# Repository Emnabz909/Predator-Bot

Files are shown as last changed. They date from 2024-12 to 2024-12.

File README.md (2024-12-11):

# Heat-Seeking Predator Bot

This project involved designing and building an autonomous robot capable of tracking and following a person based on their heat signature. The bot integrates various sensors, actuators, and a custom PCB for hardware interfacing, exemplifying a multidisciplinary approach to mechatronics.

## Table of Contents
1. [Introduction](#introduction)
2. [Specifications](#specifications)
3. [Design Development](#design-development)
   - [Hardware Design](#hardware-design)
   - [Software Design](#software-design)
4. [Results](#results)
5. [Lessons Learned](#lessons-learned)
6. [References](#references)

---

## Introduction
The Heat-Seeking Predator Bot was designed to:
- Detect and follow a person using a thermal camera and IR distance sensor.
- Maintain a proximity range using motor control.
- Demonstrate multitasking capabilities for real-time operation.

The bot was built using an ESP32 FireBeetle microcontroller, with custom PCB and housing, leveraging various sensors and actuators to create a functional prototype.

## Specifications
The bot's key specifications are:
- **Thermal Camera**: Adafruit MLX90640 (20–40°C, ±5°C accuracy).
- **IR Distance Sensor**: Sharp GP2Y0A21YK0F (2–36 inches, ±0.5-inch accuracy).
- **Inertial Measurement Unit (IMU)**: Adafruit BNO055 for motion control.
- **Motors**: N20 DC motors with magnetic encoders and DRV8871 motor drivers.

### Pass/Fail Criteria
- Tracks heat signatures.
- Maintains a 2–36-inch range from objects.
- Streams thermal heatmaps to a web interface.

---

## Design Development

### Hardware Design
The custom PCB was created using KiCAD and included:
- Screw terminals for component connectivity.
- Proper trace sizing for power and heat dissipation.
- Compact layout to minimize weight and improve balance.

The bot’s housing was designed to securely hold all components while minimizing weight-induced friction.

### Software Design
The software was modular, focusing on individual sensor functionality before integration:
- **Thermal Camera**: Detected heat signatures and converted data to ASCII for debugging.
- **IR Distance Sensor**: Measured distance using voltage-to-distance calibration.
- **IMU**: Provided acceleration data to refine motor control.
- **Motor Control**: Implemented PID for speed adjustments.

Due to time constraints, full system integration was not achieved.

---

## Results
While the bot's PCB design required significant revisions, the sensors functioned as expected when tested individually. Challenges included:
- Inadequate motor speed and torque.
- Integration of components due to missing PCB features.

Despite these setbacks, the project provided valuable hands-on experience.

---

## Lessons Learned
Key takeaways include:
1. **Early Planning**: A thorough design phase and literature review are essential.
2. **PCB Design**: Focus on component connectivity, power handling, and adequate debugging options.
3. **Prototyping**: Iterative testing is vital for identifying and resolving design flaws.

---

## References
- [Adafruit MLX90640 GitHub Repository](https://github.com/adafruit/Adafruit_MLX90640)
- [Adafruit BNO055 GitHub Repository](https://github.com/adafruit/Adafruit_BNO055)
- [Predator Bot Repository](https://github.com/Emnabz909/Predator-Bot)

---

## Acknowledgments
This project was completed as part of ME 507 at Cal Poly San Luis Obispo. Special thanks to the Mechatronics Department for providing resources and support.

---

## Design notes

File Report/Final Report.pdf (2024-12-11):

# ME 507 Term Project

Heat Seeking Predator Bot

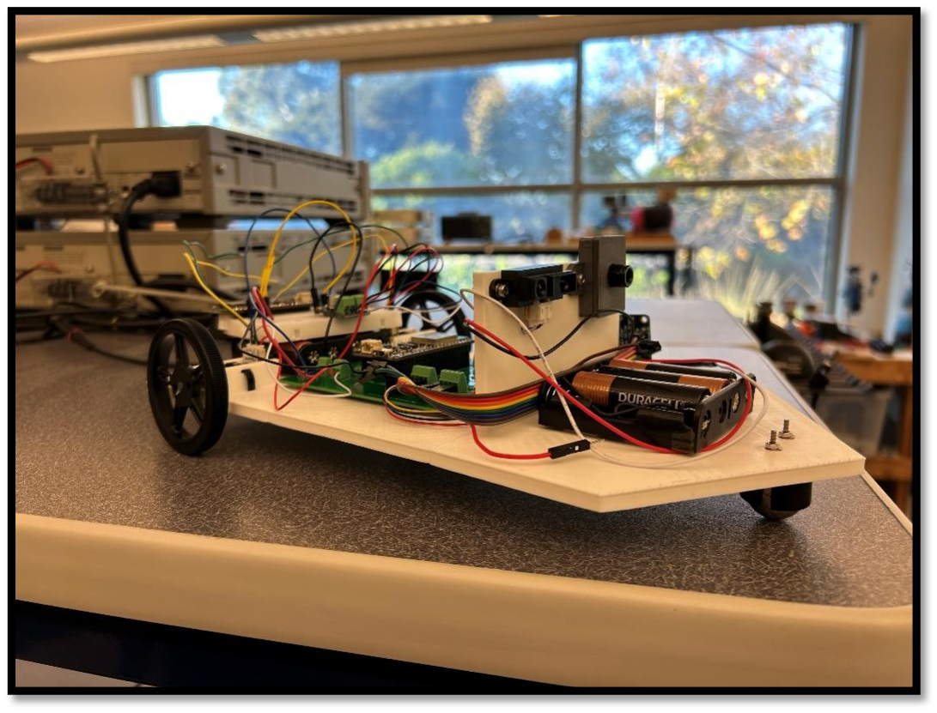
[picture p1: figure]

Created by:

Emmanuel Baez

Joseph Balderama

Mechanical Engineering

Cal Poly San Luis Obispo

December 10, 2024

## Table of Contents

## Introduction

This quarter we set out to create an autonomous robot that would track a person and continuously follow them. We intended to do this by using a thermal camera to identify a person, as well as an infrared distance sensor to be able to keep track of how far that person is. We used two DC motors with magnetic encoders so that the robot could pursue the individual as well as an Inertial Measurement Unit, IMU, to help with motor controls. We were given the ESP32 Firebeetle as the microcontroller of choice for this project. With this microcontroller and sensors in mind, we designed a PCB as well as developed the code to bring the Predator Bot to life.

The motivation behind the design of this project was not only because of our desire to achieve a bot capable of following a person, but also due to the availability of parts readily available to us already. The project began with the idea of using a thermal camera provided by the mechatronics department and using it to our advantage of achieving a follow bot. Since some follow bots use sonar location or other forms of infrared signals, we found it be a promising idea to make use of an object’s heat signature to be the primary source of signal acquisition for the bot. The project is visioned to be small but could be increased to be used by a variety of stakeholders who are interested in having a bot follow them around automatically. This bot, with the right modifications, can be used to carry loads, and stay with a reasonable range for a user. Other than these specific uses, this bot is envisioned merely as an interesting project that features multiple sensors and motors. The most outstanding expectation for this project is that it will be able to successfully achieve multitasking capabilities without any studder between the actions desired from the bot.

## Specifications

We started the project with the intention of creating a robot that uses heat signatures read by a thermal camera to identify a person, as well as a distance sensor to make sure the robot stays in the person’s proximity. It stays in proximity with two independent motors as well as a ball caster which is there for stability purposes. To ensure smooth motor controls, we are also implementing an Inertial Measurement Unit, IMU. We went in with the project with the following specifications for our sensors and for our robot.

Table 1: Measurement Specifications

Parameters | Range | Accuracy | Update Frequency | Test Method
Temperature (°C) | 20-40 | ±5 | 30 | Compare Thermal camera readings to a controlled environment.
Acceleration 2 (ft ∕ s ) | 0-0.5 | ±0.01 | 60 | Test the IMU by putting it on a linear track.
Distance (in) | 2-36 | ±0.5 | 60 | Verify the distance sensor by measuring readings against a measuring tape or ruler.

Table 2: Robot Pass/ Fail Criteria

Requirement | Criteria | Test Method
Tracks heat signature | Pass/Fail | Have a person move around to see if robot tracks body’s heat signature.
Detects objects in a 2-36 in range | Pass/Fail | Move the robot toward and away an object to verify that the distance is being measured.
Communicates thermal heat signatures to web server | Pass/Fail | Verify live heatmap on web page using a test web page.

## Design Development

This section will discuss the goal, process, and expectations for the project’s hardware and software design development. The following two sections will feature a brief discussion of the options considered, with detailed description of what our chosen design came to be.

## Hardware Design

This project initially began with the need for breakout boards for mostly all components for proof of concept. Afterwards, we began to design our own PCB and housing to make this project come to life as we envisioned. The first step following the creation of our partial specification list of this project was to generate a reasonable schematic of the connections needed to achieve desired communication between components. The purpose of this schematic is generally to understand which pins between sensors, motors, and the microcontroller will connect to each other as seen in Figure XX.

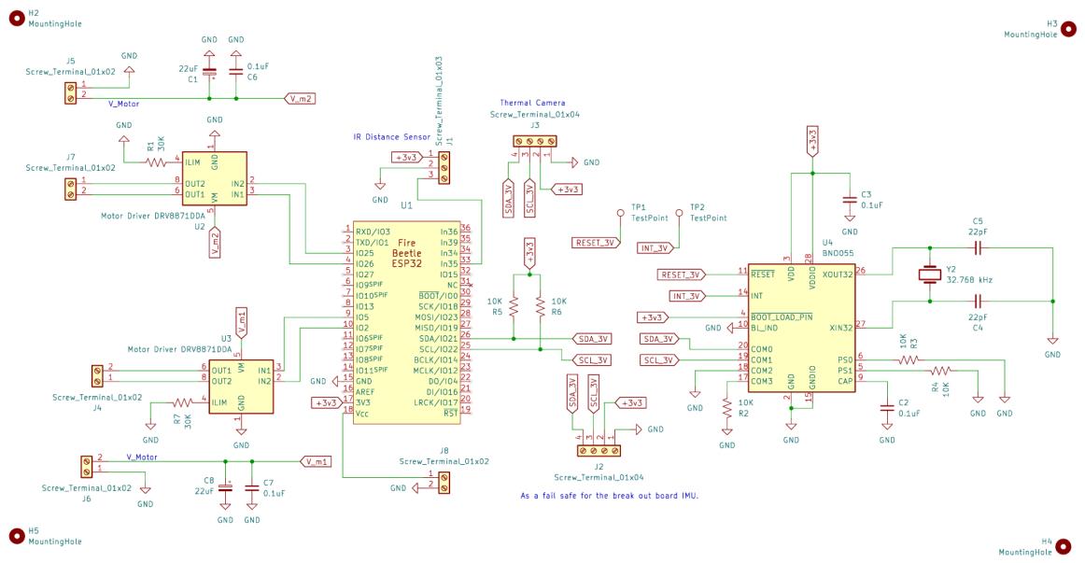
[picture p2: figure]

Figure XX: Schematic of the predator bot for designing the connections between the components.

Once we had a verified schematic of our term project, it was essential that we went through each symbol placed and chose adequate footprints to use for our PCB design. This was a very crucial step in the PCB design because we need to acknowledge what sizes of components were feasible to achieve the desire specifications of this project. For example, if we wanted to use a 0.1 uF capacitor rated for a high number of volts, we would not be able to use a very small track pad, so choosing an adequate footprint will ensure we don’t experience issues with component compatibility. The PCB design featured many steps such as placing the components and connecting everything with traces. The process of doing this was more involved than just simply connecting components. We needed to consider voltage ratings, placement/orientation, and thermal properties of this board design. For traces expected to have current flow through them, we would need to make them larger to ensure there isn’t excessive heat buildup. With the heat topic in mind, we also needed to ensure that the motor drivers had proper heat dissipation, in which we had to carefully place vias between the copper plates to allow for heat to leave the chips and be exited through convection in the air. The last consideration was the placement and orientation of the individual components. This stage did not have a right or wrong way of doing it, but rather more of an art form really. The board can be as large as desired to ensure space for everything to connect, but we needed the board to be as compact as possible to reduce weight imbalances. After many iterations of the board design, the final board design can be seen in Figure XX, where it features 7 screw terminals, 2 pads for motor drivers with appropriate use of vias to serve as a heat sink, 1 pad for the BNO05 chip used in the IMU, and many surface mount spots for various resistors and capacitors.

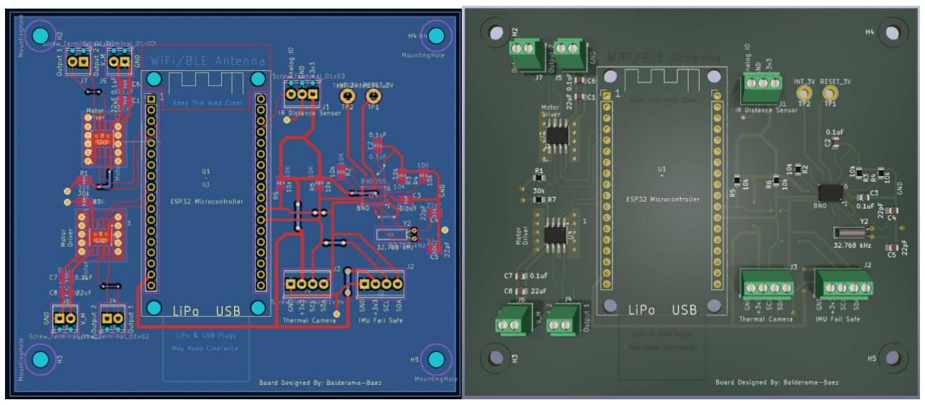
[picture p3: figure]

Figure XX: PCB design for the predator bot featuring a 2D design using KiCAD (Left) and a 3D rendered model of our expected outcome of the board (Right).

Once our board design was finalized, we could begin the process of designing housing to mount and connect all of our built or bought components. The housing needed to be large enough that it would hold everything without unnecessary congestion, but small enough that it didn’t add excessive weight to the bot and put more stress on the motors. The board design went through multiple iterations, but it was chosen to have a flat base pate, with two rectangular slots to hold the two motors in with the use of zip ties. The base plate also included 4 mounting holes in the center of the plate to mount the finished PCB board, which allowed for some variability of connections between the components. Additionally, the model had a vertical rectangular plate that served merely as a mounting bracket for the thermal camera and distance sensor. Both IR sensors were mounted using fasteners and through holes seen in the vertical plate. The last feature of the base plate was two mounting holes used for attaching the ball caster wheel to the plate using fasteners. The final model design for the housing can been seen in Figure XX.

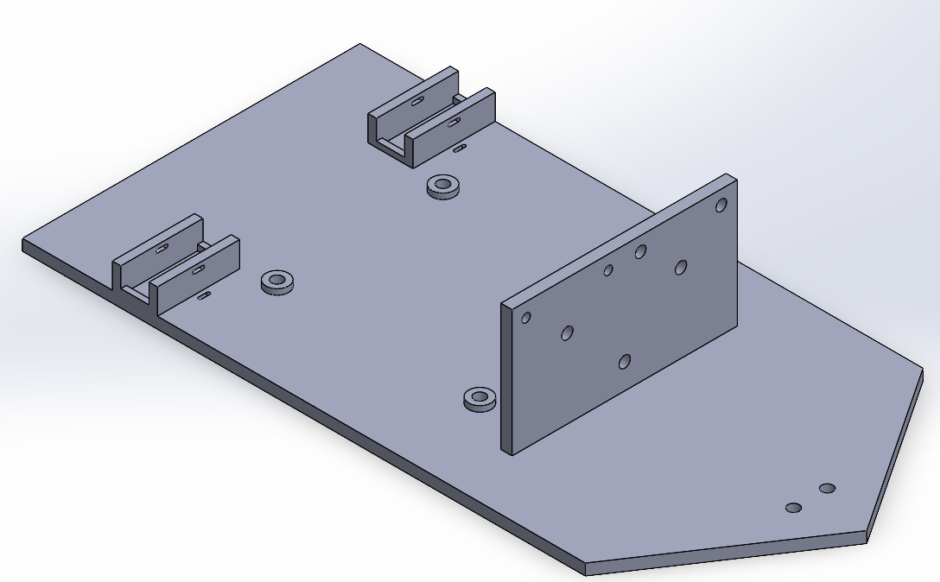
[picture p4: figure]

Figure XX: Isometric view of the Predator Bot baseplate that features mounting spots for components of this project.

These hardware designs were an essential step to achieving this project and allowed us to move forward with the project and begin the steps to achieve successful software design.

## Software Design

When we first started this project, we believed the best course of action was to get each sensor to work separately, and then at the end integrate them together. This has left us with code for each sensor, but not much for the overall robot. One of the sensors we first were able to get to work was for the IMU. The specific model we used was the Adafruit BNO055. The one nice thing about this sensor is its ease of use and the many resources out there for it. We were able to use Adafruit’s public repository on GitHub to learn how to use this sensor. The BNO055 is composed of many other sensors like an accelerometer, gyroscope, and even a magnetometer. So, the hard part of using this IMU is knowing how to get the data you want from the sensor. Luckily with the GitHub repository, we can find the I2C address for any of the sensors we wanted. We were more interested in using the acceleration data the sensor can provide, in hopes of using the robot's acceleration in each axis to refine the motor control.

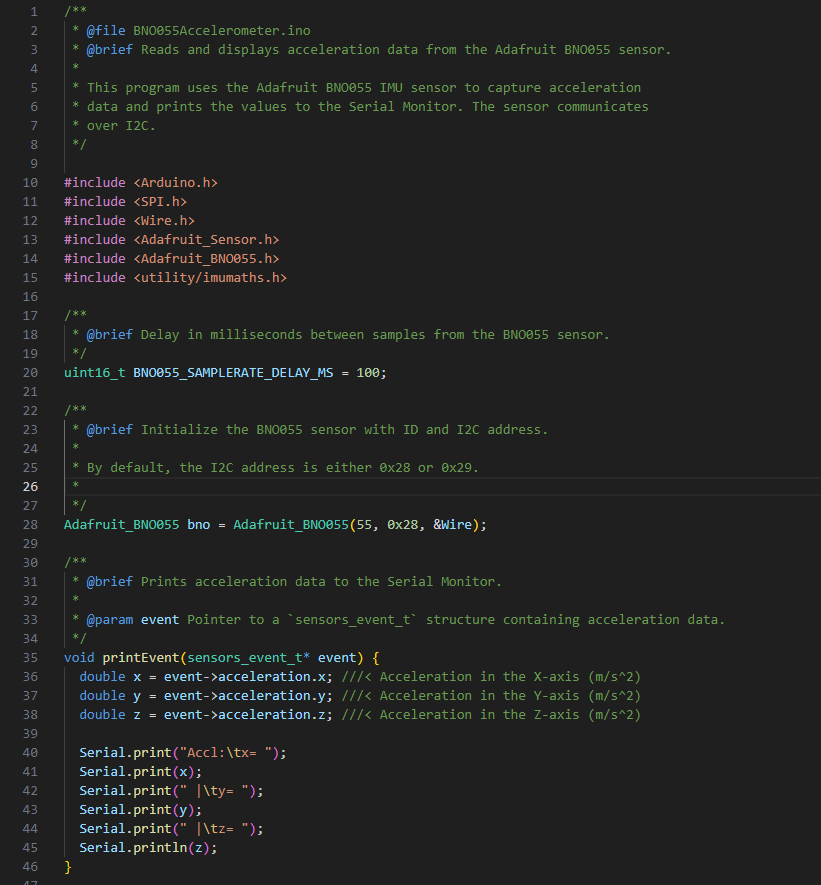
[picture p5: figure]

Figure X: A snippet of the setup code for the IMU. The reason the I2C address is either 0x28 or 0x29 is because if you check the BNO055 repository, you can see that those two addresses correlate to the least and most significant bit for the x linear acceleration data as well as the start for the linear acceleration data registers.

One of the other sensors we got to work early on was the IR distance sensor. This sensor was a bit weird to work with because it worked off specifically off an analog pin. The reason this is weird is because analog pins can measure a range of voltages. So, when coding for this sensor we needed a way to convert the what the analog sensor is reading into a voltage and then convert that voltage into a distance.

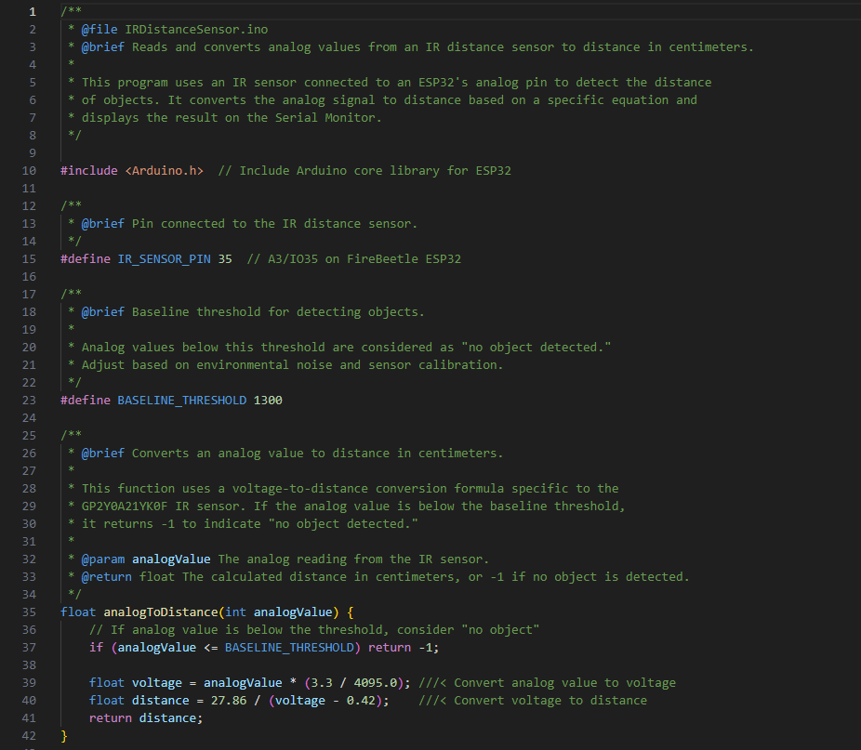
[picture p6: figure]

Figure X: A snippet of code from our IR distance sensor. So, we set a value for how far our sensor could “see” as well as set up a function that converts what is being read to a voltage and then that voltage gets turned into a distance. The voltage is calculated based on the 3.3V it takes to operate the sensor as well as 4095 being the max value for a 12-bit ADC. The 27.86 for the distance comes from a calibration constant as well as the 0.42 being and offset to account for the sensor’s non-zero voltage range.

The one part that took us the most time to figure out were the motors. We used N20 DC motors with Magnetic Encoders with a 1:50 gear ratio. For testing we paired these motors with the DRV8871 DC Motor Driver. The biggest issue between the motor and the motor driver was understanding how to connect everything. Once we understood how the motors should be connected, we had to understand how the pulse width modulation, PWM for these motors. From what we found out during our testing is that the motors we were using had two motor inputs for two different PWM signaling. What made us stuck for a while was that when we were conducting our testing for the motors, we had initially set the two motor inputs to be on high. This caused the motor to not function at all, and we learned for it to spin the motors, we needed to set one input to high and the other to low. Once we made that change, we noticed we can get the motor to spin in the other direction by reversing the inputs and setting the other input to low and the other to high.

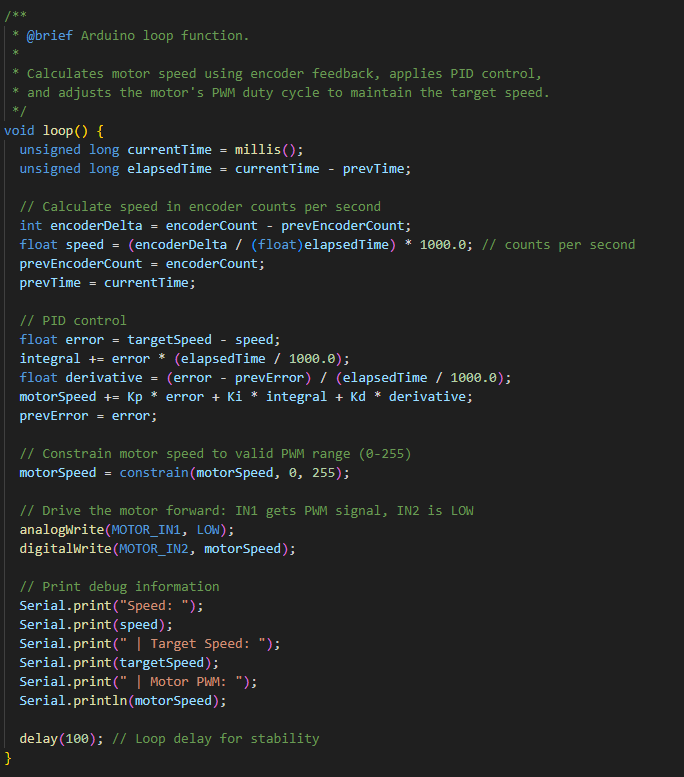
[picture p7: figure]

Figure X: A snippet of code for our motor controls. For this iteration of the code, we tried to use PID controls to adjust the speed of the motors. So, for PID controls we find the error of desired speed and current speed, the accumulated error over time, as well as the rate of change for the error. These along with Kp, Ki, and Kd constants we set in the setup help calculate the adjustments for our motor. We also try to limit the calculated motor speed in range of a valid PWM range since our microcontroller uses an 8-bit timer for generating a PWM signal.

The last sensor used was the Thermal camera. This sensor works very similar to the IMU in sense that they both use I2C. So similarly to debugging the IMU, we needed additional libraries to see how the thermal camera functioned. The Thermal camera we used was an Adafruit MLX90640, and Adafruit also had a repository for it on GitHub. One thing we did to help in the debugging process was assigning heat temperatures an ASCII symbol. This makes it so instead of a block of numbers being printed a low-resolution image can be captured.

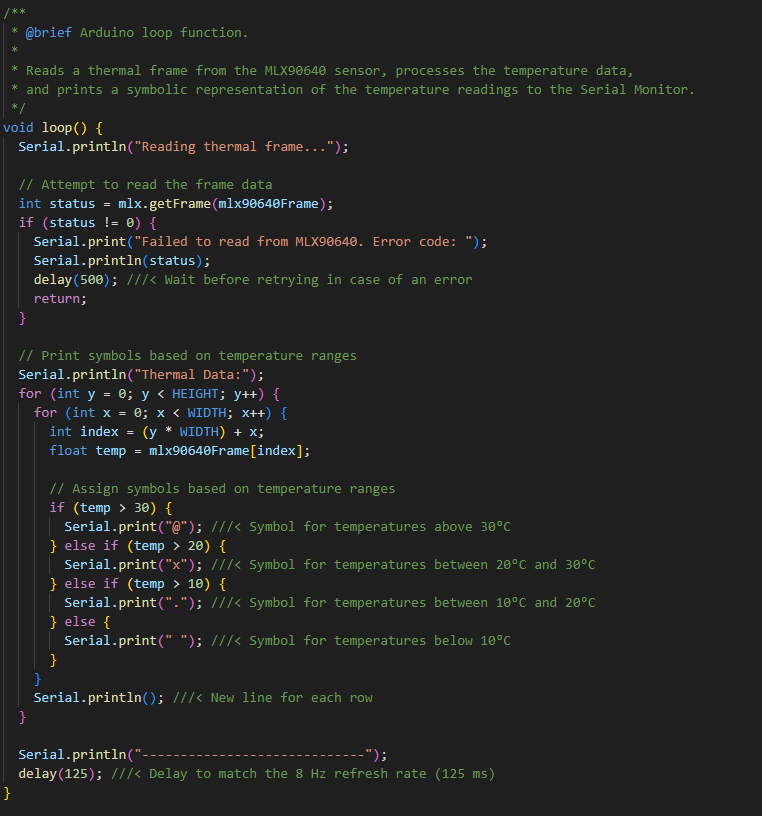
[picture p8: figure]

Figure X: A snippet of code for our thermal camera code. This is the loop function that is reading the data from the thermal camera and assigning those values an ASCII symbol. The range of temperatures comes from initial testing of the sensor. The average body temperature is 37°C and the average room temperature is 20°C, so we made it easier to capture what we assumed were body temperatures, but the sensor could see a hotter signature and assume it is a person.

One function we hope to do alongside our thermal camera was to have the ASCII heat signature streamed to a website, so that people could see what the robot is looking at. Creating the webserver wasn’t the hardest issue, it was more about getting the data transferred. We created a test code using the example given to us on canvas and tried to use that as a reference in creating our own web server. Unfortunately, we weren’t able to get done in time.

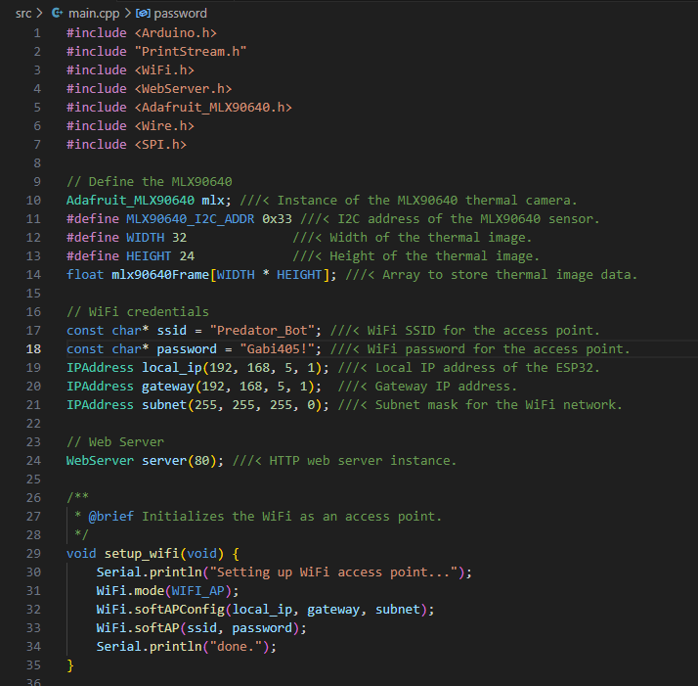
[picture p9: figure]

Figure X: A snippet of code for creating the web server. So instead of making the thermal camera a separate class, we tried to recreate it alongside the code that would generate and manage the webpage. This code tries to make use of the ESP32 Wi-Fi capabilities letting the ESP32 create its own Wi-Fi network. So, an individual could look for Wi-Fi connections on any of their devices and should see “Predator_Bot” as one they could join. Once connected they could open any browser and type in the IP address and that they would be taken to the webpage associated with our bot.

Although we got each individual sensors to work on their own, we had little time to integrate them together. We would have created a class for each sensor and used the given code to create tasks and shares. Although we did not get to implement it, we did have a task diagram outlining what we believed to work for our robot.

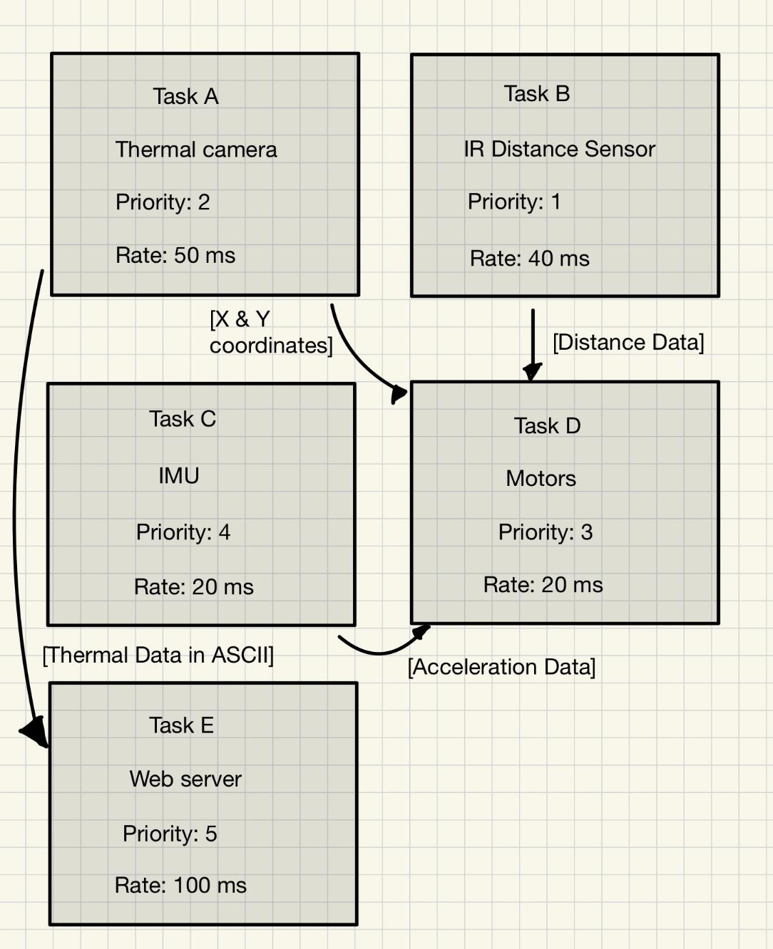
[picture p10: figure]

Figure X: Task Diagram for our robot.

## Results

The results of this project were far from straightforward, but the process exemplified Cal Poly’s “Learn by Doing” philosophy. From the outset, the PCB design for the bot faced significant challenges. While the PCB included all the major components necessary for the project to function, it lacked several minor but critical elements. Missing features included screw terminals, grounded pins, and essential connections for communication and power. To address these shortcomings, we had to manually solder jumper wires to create operational connections. Despite these adjustments, we were able to power and integrate the IMU, distance sensor, and thermal camera. These sensors communicated adequately with the microcontroller, producing reasonable outputs on the computer.

However, issues arose with the motors and their connections to the motor driver and microcontroller. We discovered that our design lacked a way to power the motor drivers and monitor or adjust the motor encoders, which were critical for achieving the project’s intended functionality. To address this, we used motor driver breakout boards and jumper wires with a circuit board to enable some degree of motor control via PWM signal adjustments. Once the motors were operational, a new challenge emerged: the motors’ maximum speed was too low for the project specifications, and their torque was insufficient to overcome internal friction and the bot’s weight-induced friction on the wheels.

Although the final results fell short of our original vision, the project offered invaluable lessons. In hindsight, the design phase required greater attention and would be approached differently in the future. Conducting a more thorough literature review and performing preliminary hand calculations would be essential for developing a successful design. We now recognize the importance of the early stages of project development in achieving desired outcomes.

For PCB design, we learned that a clear conceptualization of how all components connect is crucial. Power traces often require more consideration than communication traces, and future designs should include screw terminals to accommodate breakout boards, reducing the likelihood of overlooked features.

Despite its challenges, this project was one of the most enjoyable experiences we’ve had. The lessons learned have strengthened our understanding of mechatronics, and we look forward to applying this knowledge to future projects.

## Appendices

## A. Links

Adafruit. “Adafruit/ADAFRUIT_MLX90640: MLX90640 Library Functions.” GitHub, github.com/adafruit/Adafruit_MLX90640. Accessed 9 Dec. 2024.

Adafruit. “Adafruit/ADAFRUIT_BNO055: Unified Sensor Driver for the Adafruit BNO055 Orientation Sensor Breakout.” GitHub, github.com/adafruit/Adafruit_BNO055. Accessed 9 Dec. 2024.

Our repository at https://github.com/Emnabz909/Predator-Bot

## B. Specification List

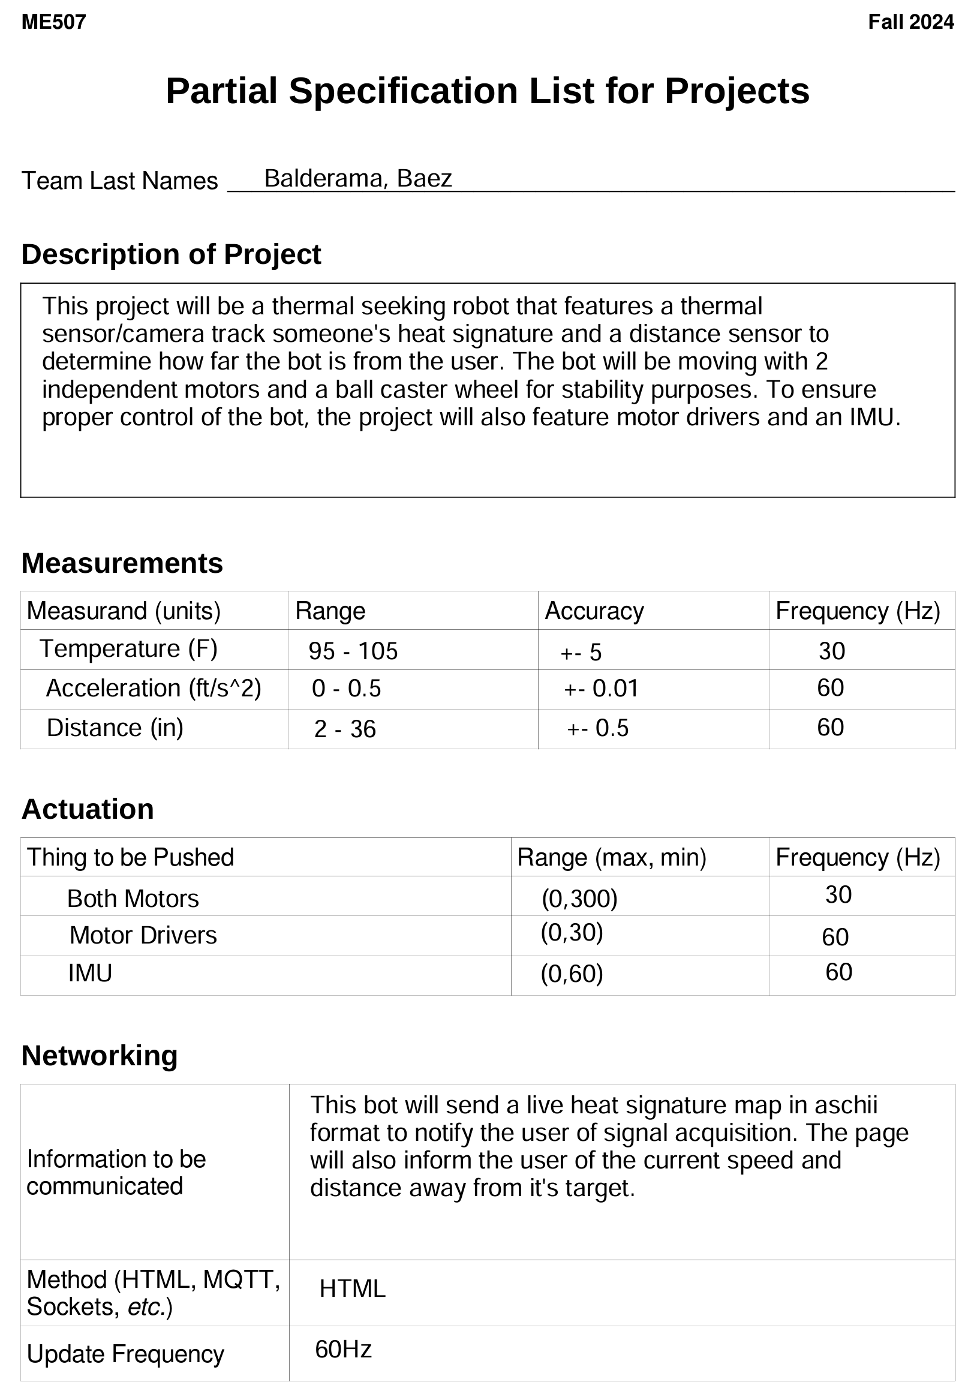
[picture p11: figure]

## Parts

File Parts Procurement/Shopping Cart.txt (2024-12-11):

Parts to be ordered:

Capacitor(s)
2X - 22uF (polarized)
https://www.digikey.com/en/products/detail/samsung-electro-mechanics/CL21A226MQQNNNE/3886758
4X - 0.1uF
https://www.digikey.com/en/products/detail/yageo/CC0805KRX7R9BB104/302874
2X - 22pF
https://www.digikey.com/en/products/detail/kemet/C0805C220J5GAC7800/411112

Resistor(s)
2X - 30K
https://www.digikey.com/en/products/detail/koa-speer-electronics-inc/RK73B2ATTD303J/10236581
5X - 10k
https://www.digikey.com/en/products/detail/stackpole-electronics-inc/RNCP0805FTD10K0/2240262

1X - Crystal Oscillator 32.768 kHz with 22pF load capacitance
https://www.digikey.com/en/products/detail/epson/C-005R-32-7680K-D-PB-FREE/7725539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

1X - BN005 Chip
https://www.digikey.com/en/products/detail/bosch-sensortec/BNO055/6136301

2X - Motor Driver Chips
https://www.digikey.com/en/products/detail/texas-instruments/DRV8871DDA/6110574

Screw Terminals
4X - 2 pin
https://www.digikey.com/en/products/detail/phoenix-contact/1725656/267462
1X - 3 pin
https://www.digikey.com/en/products/detail/phoenix-contact/1725669/267463
2X - 4 pin
https://www.digikey.com/en/products/detail/phoenix-contact/1725672/267464

Spare Soldering Pin Headers?
?X - 18 Pins

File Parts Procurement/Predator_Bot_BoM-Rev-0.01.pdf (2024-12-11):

Project:

Qty. | Description | Price ea. ($) | Source | Link | Supplementary Info.

215321&gad_source=1&gclid=CjwKCAjw68K4BhAuEiwAylp3kqLtBv9Mcqa8VyTQtvasQ4 OTto2lUcIb7RUtWoE9WC_lcdbkX058fBoCCMsQAvD_BwE
1 | IR Thermal Camera | $ | 74.95 | Adafruit | https://www.adafruit.com/product/4407 | Will borrow from 405 lab

GuhJY71GAdwtxIzIyvBFb4fo2Yoc916JQiZ0ZlCf2Fdz5GXoV3_sYZM8xvjyO6E0iL1j1LbqKN 8lN1HrPkQTpTVSZ4iO45jLqTSuzb9bTfJRTTf3lcPngdBWIc13Hb4BwMuwrjKnU5w8W6KM WnKIRs40Jabogv8qciq8yk7lBgXX5vxzq5KosPRCKxm7iybvn1KySOu1qSWTuoUtDU3lBr0l hc_H3qY3B_rCs.HULrXi77SE_K3c4Yhys2T6Qj7fBrctW50pcjrBcR5Nw&dib_tag=se&keyw ords=roll+of+PLA&qid=1729212035&sprefix=roll+of+pla%2Caps%2C229&sr=8-3

Mechanical Parts
2 | DC Motor w/ Magnetic Encoder | $ 25.00 | Adafruit | https://www.adafruit.com/product/4638
1 | Ball Caster - 3/4" Metal Ball | $ 4.95 | Adafruit | https://www.adafruit.com/product/1200
2 | Black Multi-Hub Wheel for TT / Lego or N20 Motor - 65mm Diameter | $ | Adafruit 1.95 | https://www.adafruit.com/product/4205
1 Roll of PLA | | 14.00 $ | Amazon | https://www.amazon.com/OVERTURE-Filament-Consumables-Dimensional-Accuracy/dp/B07PGY2JP1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

Predator Bot

Electronic Parts

1 | Breadboard & Jumper Wires | 10.00 $ | Amazon | https://www.amazon.com/dp/B08Y59P6D1?ref=ppx_yo2ov_dt_b_fed_asin_title
1 | IR Distance sensor | $ 15.00 | Adafruit | https://www.adafruit.com/product/164
2 | DC Motor Driver Breakout Board | $ 7.50 | Adafruit | https://www.adafruit.com/product/3190
1 | Fire Beetle Board - ESP 32 | $ - | Cal Poly | N/A
4 | Resistors | 0.10 $ | DigiKey | https://www.digikey.com/en/products/filter/chip-resistor-surface-mount/52 | 30k (x2)
4 | Capacitors | 0.10 $ | DigiKey | https://www.digikey.com/en/products/filter/ceramic-capacitors/60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 BiIAuqQA4AuUIAVQB2ASx4B5TAFlC2fAFcAToRABfdUA | 0.1μF(x2), 47μF(x2)
4 | Screw Terminals | 1.04 $ | Mouser Electronics | https://www.mouser.com/ProductDetail/Phoenix-Contact/1729128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

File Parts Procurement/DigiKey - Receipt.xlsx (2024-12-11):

# | QUANTITY | PART NUMBER | MANUFACTURER PART NUMBER | DESCRIPTION | CUSTOMER REFERENCE | BACKORDER | UNIT PRICE | EXTENDED PRICE
1 | 15 | 1276-1100-1-ND | CL21A226MQQNNNE | CAP CER 22UF 6.3V X5R 0805 |  | 0 | 0.068 | 1.02
2 | 15 | 311-1140-1-ND | CC0805KRX7R9BB104 | CAP CER 0.1UF 50V X7R 0805 |  | 0 | 0.033 | 0.50
3 | 15 | 399-C0805C220J5GACTUCT-ND | C0805C220J5GACTU | CAP CER 22PF 50V C0G/NP0 0805 |  | 0 | 0.041 | 0.62
4 | 15 | 2019-RK73B2ATTD303JCT-ND | RK73B2ATTD303J | RES 30K OHM 5% 1/4W 0805 |  | 0 | 0.026 | 0.39
5 | 20 | RNCP0805FTD10K0CT-ND | RNCP0805FTD10K0 | RES 10K OHM 1% 1/4W 0805 |  | 0 | 0.027 | 0.54
6 | 2 | 828-1058-1-ND | BNO055 | IMU ACCEL/GYRO/MAG I2C 28LGA |  | 0 | 14.73 | 29.46
7 | 4 | 296-44509-5-ND | DRV8871DDA | IC MOTOR DRVR UNIPLR 8SO PWRPAD |  | 0 | 2.92 | 11.68
8 | 5 | 277-1273-ND | 1725656 | TERM BLK 2P SIDE ENT 2.54MM PCB |  | 0 | 1.68 | 8.40
9 | 2 | 277-1274-ND | 1725669 | TERM BLK 3P SIDE ENT 2.54MM PCB |  | 0 | 2.51 | 5.02
10 | 3 | 277-1275-ND | 1725672 | TERM BLK 4P SIDE ENT 2.54MM PCB |  | 0 | 3.34 | 10.02

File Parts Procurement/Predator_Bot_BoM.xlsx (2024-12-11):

Shopping list: |  | https://www.digikey.com/en/mylists/list/MFPQYEQ2Q4 |  |  | Passkey: jb&emF24
 |  | http://www.adafruit.com/wishlists/599587
Project: | Predator Bot
Qty. | Description | Price ea. ($) | Source | Link | Supplementary Info.
Electronic Parts
1 | Breadboard & Jumper Wires | $10.00 | Amazon | https://www.amazon.com/dp/B08Y59P6D1?ref=ppx_yo2ov_dt_b_fed_asin_title
1 | IR Distance sensor | $15.00 | Adafruit | https://www.adafruit.com/product/164
2 | DC Motor Driver Breakout Board | $7.50 | Adafruit | https://www.adafruit.com/product/3190
1 | Fire Beetle Board - ESP 32 | $0.00 | Cal Poly | N/A
1 | Resistors | $0.10 | DigiKey | https://www.digikey.com/en/products/filter/chip-resistor-surface-mount/52 | 30k (x2), 10k (5x)
1 | Capacitors | $0.10 | DigiKey | https://www.digikey.com/en/products/filter/ceramic-capacitors/60 | 0.1μF(x4), 22μF (x2), 22pF(x2)
4 | Screw Terminals | $1.04 | Mouser Electronics | https://www.mouser.com/ProductDetail/Phoenix-Contact/1729128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 | 2 Pin (4x), 3 Pin (1x), 4 Pin (2x)
1 | IMU Breakout board | $34.95 | Adafruit | https://www.adafruit.com/product/2472
1 | BNO05 Chip | $29.46 | DigiKey | https://www.digikey.com/en/products/detail/bosch-sensortec/BNO055/6136301
2 | 4 x AA Battery Holder w/ jumper wires | $2.95 | Adafruit | https://www.adafruit.com/product/3859 | 1 to power motors and 1 to power sensors
1 | IR Thermal Camera | $74.95 | Adafruit | https://www.adafruit.com/product/4407 | Will borrow from 405 lab
Mechanical Parts
2 | DC Motor w/ Magnetic Encoder | $25.00 | Adafruit | https://www.adafruit.com/product/4638
1 | Ball Caster - 3/4" Metal Ball | $4.95 | Adafruit | https://www.adafruit.com/product/1200
2 | Black Multi-Hub Wheel for TT / Lego or N20 Motor - 65mm Diameter | $1.95 | Adafruit | https://www.adafruit.com/product/4205
1 | Roll of PLA | $14.00 | Amazon | https://www.amazon.com/OVERTURE-Filament-Consumables-Dimensional-Accuracy/dp/B07PGY2JP1
2 | Wheels | 2.5 | Adafruit | https://www.adafruit.com/product/3757
1 | Ball Caster - 3/4" Metal Ball | 4.95 | Adafruit | https://www.adafruit.com/product/1200
2 | 4 x AA Battery Holder w/ jumper wires | 2.95 | Adafruit | https://www.adafruit.com/product/3859

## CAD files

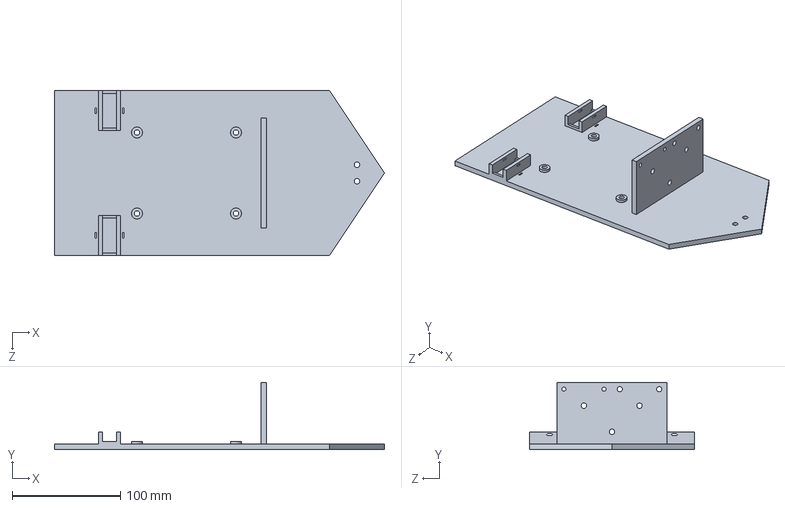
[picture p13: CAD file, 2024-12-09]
CAD/Base Plate.SLDPRT
304.8 x 62.2 x 152.4 mm

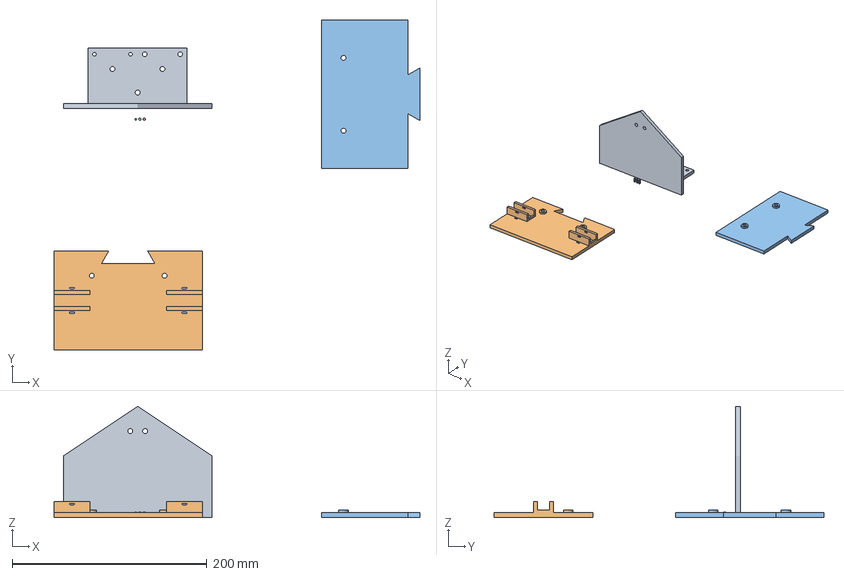
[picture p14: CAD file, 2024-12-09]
CAD/Pred_bot/Base Plate.3mf
375.9 x 338.7 x 114.3 mm
Base Plate.STL_B
Base Plate.STL_A_B
Base Plate.STL_A_A
Base Plate.STL-Dowel-Connector-1
Base Plate.STL-Dowel-Connector-2
Base Plate.STL-Dowel-Connector-3

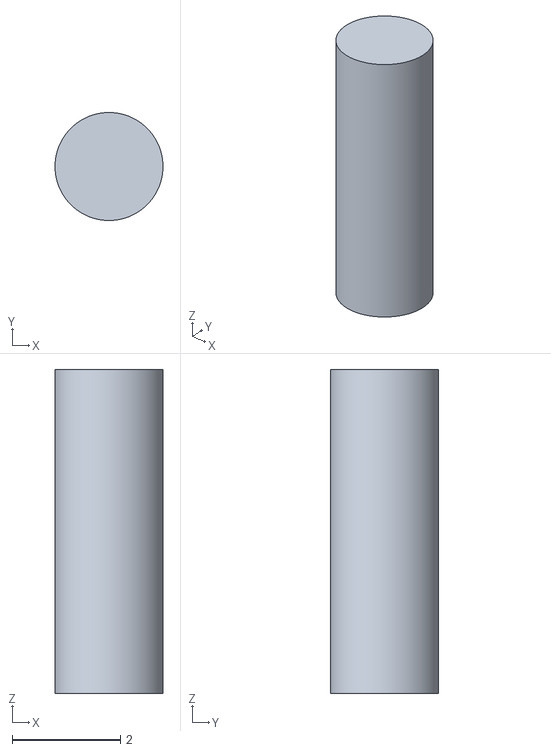
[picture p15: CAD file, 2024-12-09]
CAD/Pred_bot/Base Plate.STL-Dowel-Connector-3.stl
2.00 x 2.00 x 6.00

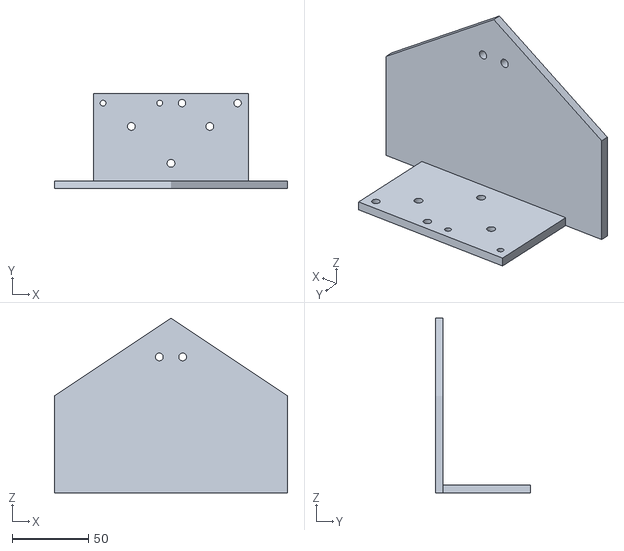
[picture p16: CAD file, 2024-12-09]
CAD/Pred_bot/Base Plate.STL_B.stl
152.4 x 62.2 x 114.3

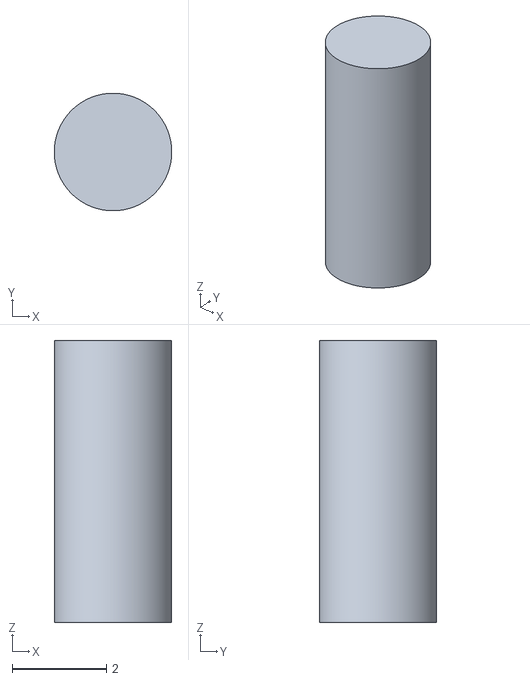
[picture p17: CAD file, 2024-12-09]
CAD/Pred_bot/Base Plate.STL-Dowel-Connector-2.stl
2.50 x 2.50 x 6.00

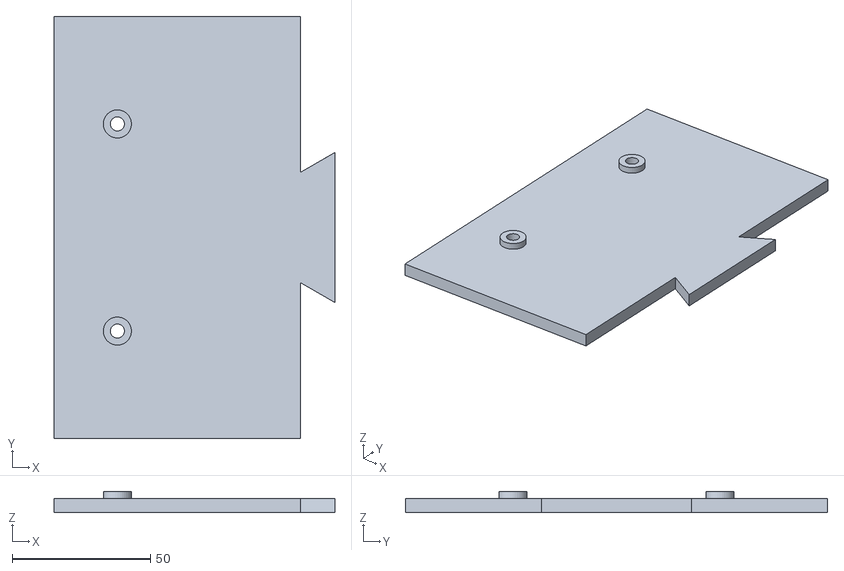
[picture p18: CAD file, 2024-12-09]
CAD/Pred_bot/Base Plate.STL_A_A.stl
101.4 x 152.4 x 7.62

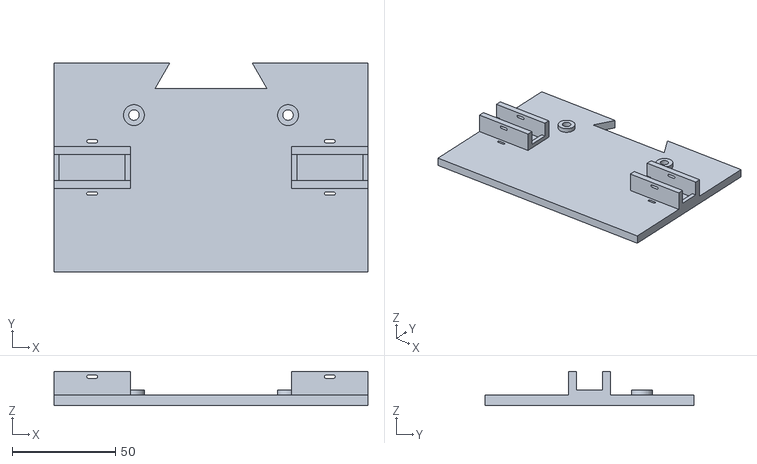
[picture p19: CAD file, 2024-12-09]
CAD/Pred_bot/Base Plate.STL_A_B.stl
152.4 x 101.5 x 16.5

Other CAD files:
CAD/Pred_bot/Base Plate.STL-Dowel-Connector-1.stl

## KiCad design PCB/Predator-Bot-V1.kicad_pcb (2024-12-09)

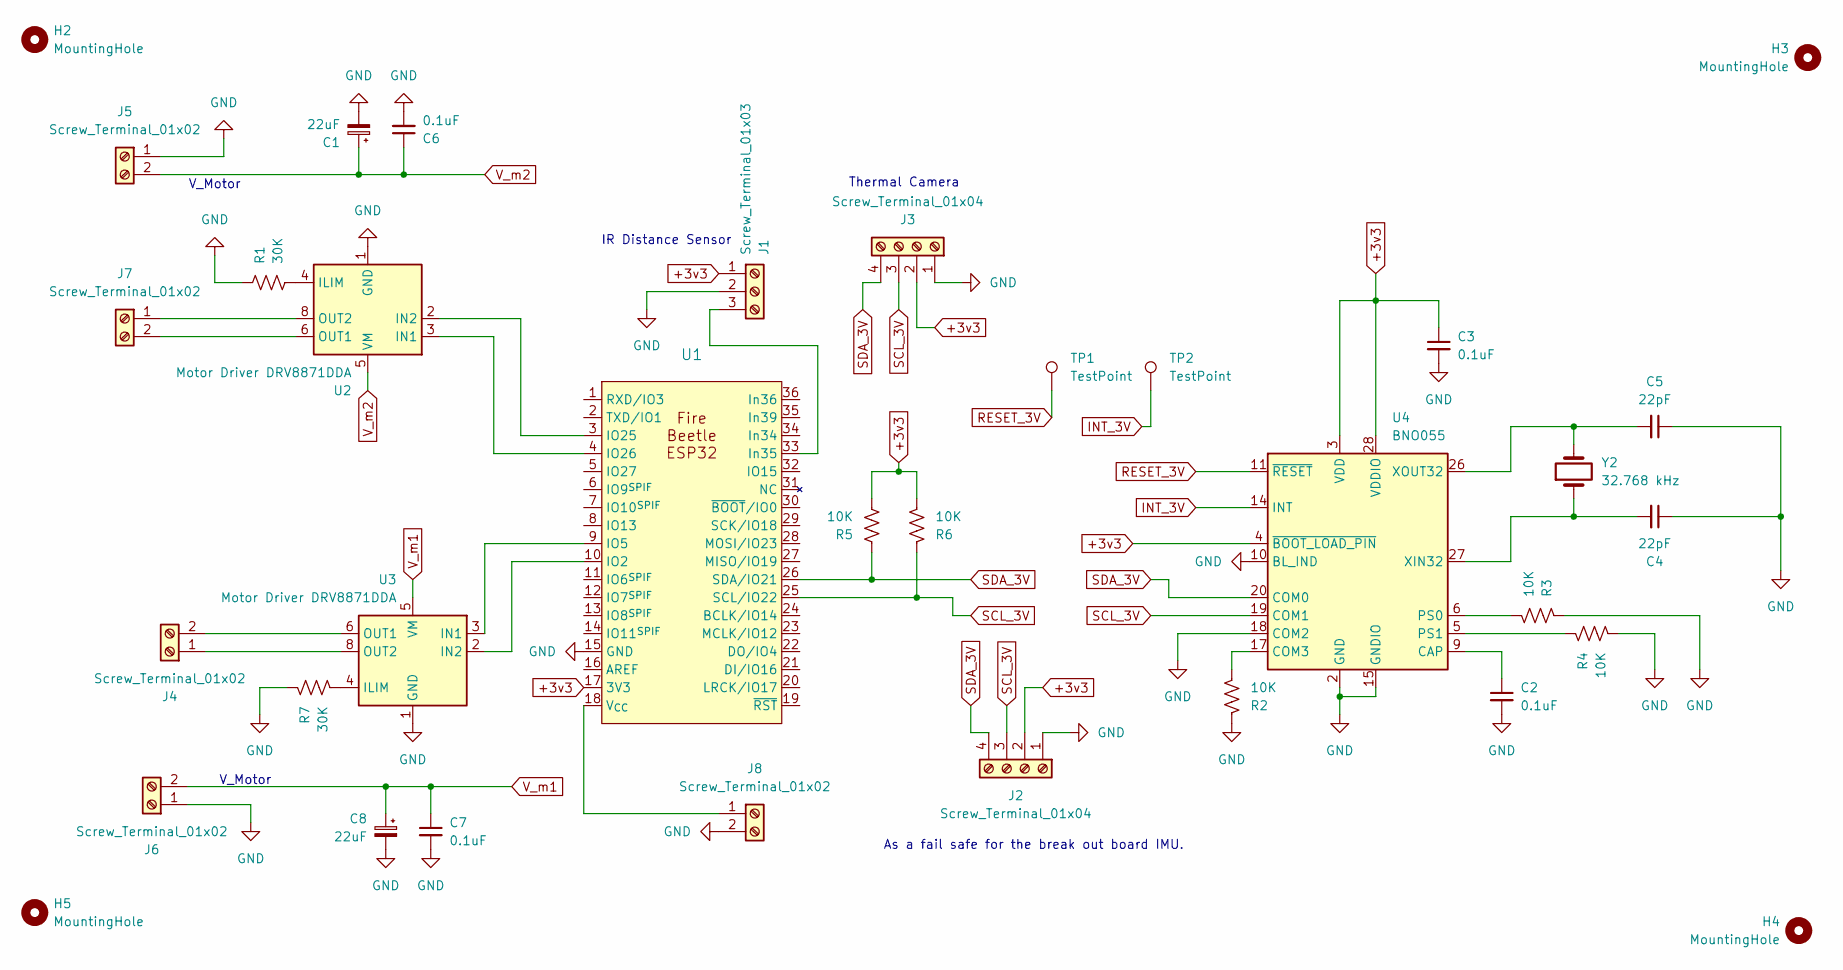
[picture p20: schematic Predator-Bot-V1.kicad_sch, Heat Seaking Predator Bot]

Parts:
C1, C8: 22uF; C_0805_2012Metric
C2, C3, C6, C7: 0.1uF; C_0805_2012Metric
C4, C5: 22pF; C_0805_2012Metric
H2, H3, H4, H5: MountingHole; MountingHole_3.5mm
J1: Screw_Terminal_01x03; TerminalBlock_Phoenix_MPT-0,5-3-2.54_1x03_P2.54mm_Horizontal
J2, J3: Screw_Terminal_01x04; TerminalBlock_Phoenix_MPT-0,5-4-2.54_1x04_P2.54mm_Horizontal
J4, J5, J6, J7, J8: Screw_Terminal_01x02; TerminalBlock_Phoenix_MPT-0,5-2-2.54_1x02_P2.54mm_Horizontal
R1, R7: 30K; R_0805_2012Metric
R2, R3, R4, R5, R6: 10K; R_0805_2012Metric
TP1, TP2: TestPoint; TestPoint_Plated_Hole_D2.0mm
U1: FireBeetle-ESP32
U2, U3: Motor Driver DRV8871DDA; Texas_HTSOP-8-1EP_3.9x4.9mm_P1.27mm_EP2.95x4.9mm_Mask2.4x3.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
U4: BNO055; LGA-28_5.2x3.8mm_P0.5mm
Y2: 32.768 kHz; Crystal_C26-LF_D2.1mm_L6.5mm_Horizontal

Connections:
+3v3: C3.1, J1.1, J2.2, J3.2, R5.2, R6.2, U1.17 (3V3), U4.3 (VDD), U4.4 (~BOOT_LOAD_PIN), U4.28 (VDDIO)
GND: C1.2, C2.2, C3.2, C4.1, C5.1, C6.2, C7.2, C8.2, J1.2, J2.1, J3.1, J5.1, J6.1, J8.2, R1.1, R2.1, R3.1, R4.2, R7.1, U1.15 (GND), U2.1 (GND), U2.7 (GND), U2.9 (GND), U3.1 (GND), U3.7 (GND), U3.9 (GND), U4.2 (GND), U4.10 (BL_IND), U4.15 (GNDIO), U4.16 (GNDIO), U4.18 (COM2), U4.25 (GNDIO)
INT_3V: TP2.1, U4.14 (INT)
unnamed: J1.3, U1.33 (In35)
unnamed: J4.1, U3.8 (OUT2)
unnamed: J4.2, U3.6 (OUT1)
unnamed: J7.1, U2.8 (OUT2)
unnamed: J7.2, U2.6 (OUT1)
unnamed: J8.1, U1.18 (V_{CC})
unnamed: U1.10 (IO2), U3.2 (IN2)
unnamed: U1.9 (IO5), U3.3 (IN1)
unnamed: U1.3 (IO25), U2.2 (IN2)
unnamed: U1.4 (IO26), U2.3 (IN1)
unnamed: R1.2, U2.4 (ILIM)
unnamed: R7.2, U3.4 (ILIM)
unnamed: C2.1, U4.9 (CAP)
unnamed: R2.2, U4.17 (COM3)
unnamed: R3.2, U4.6 (PS0)
unnamed: R4.1, U4.5 (PS1)
unnamed: C4.2, U4.27 (XIN32), Y2.1
unnamed: C5.2, U4.26 (XOUT32), Y2.2
RESET_3V: TP1.1, U4.11 (~RESET)
SCL_3V: J2.3, J3.3, R6.1, U1.25 (SCL/IO22), U4.19 (COM1)
SDA_3V: J2.4, J3.4, R5.1, U1.26 (SDA/IO21), U4.20 (COM0)
V_m1: C7.1, C8.1, J6.2, U3.5 (VM)
V_m2: C1.1, C6.1, J5.2, U2.5 (VM)

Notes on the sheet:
IR Distance Sensor
As a fail safe for the break out board IMU.
V_Motor
Thermal Camera

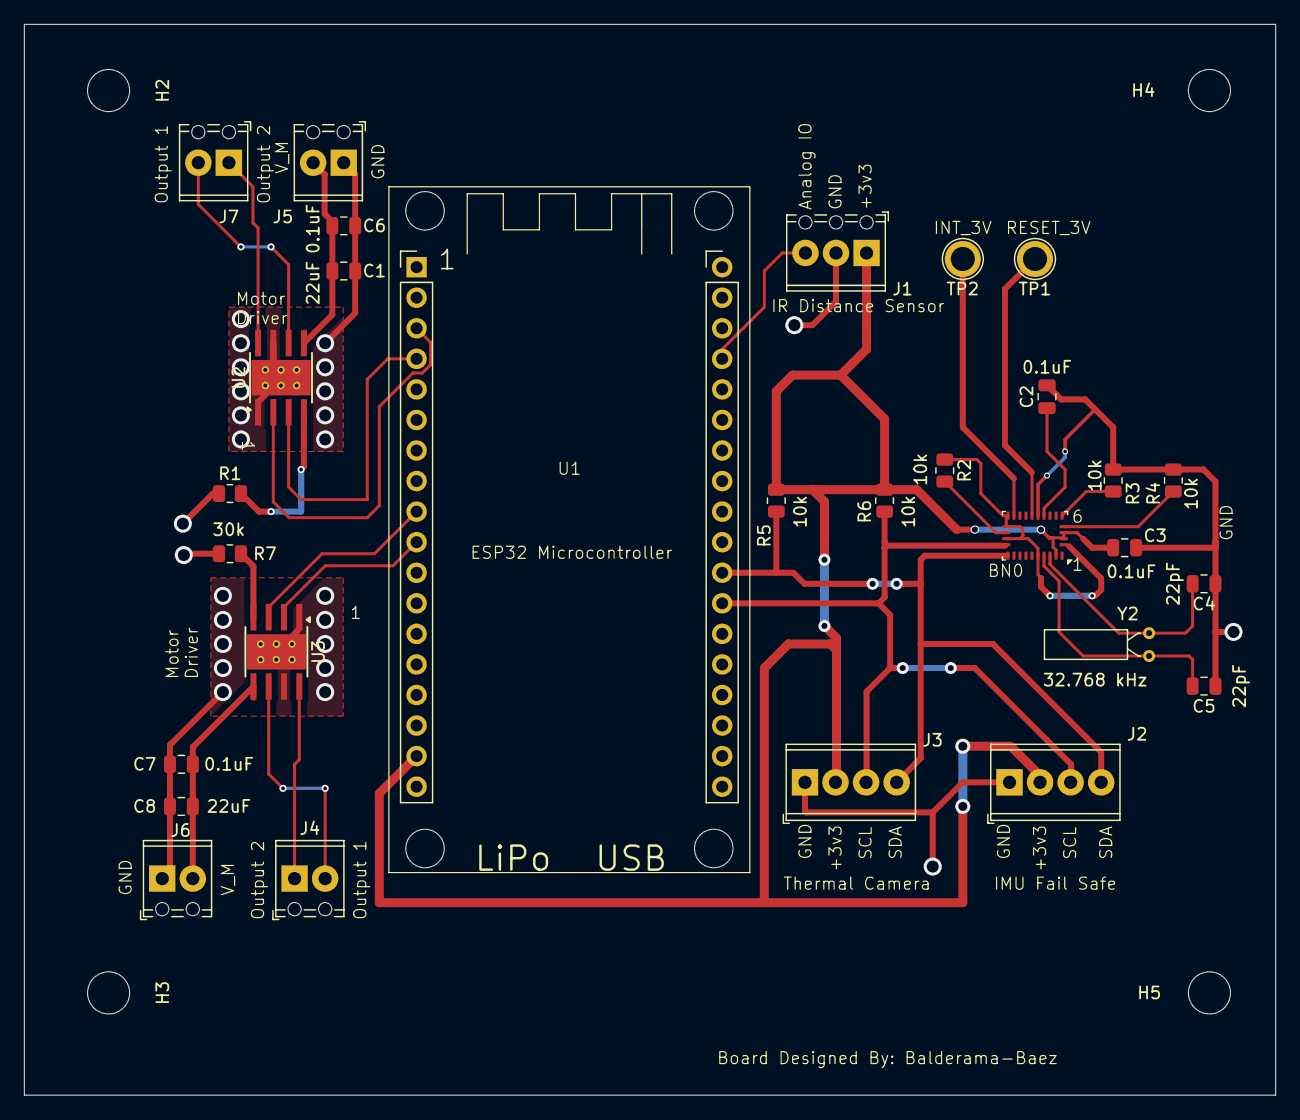
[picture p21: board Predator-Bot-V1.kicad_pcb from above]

Board: 2 copper layers, 104.0 x 89.0 mm, 33 parts (0 on the bottom side), 25 nets.

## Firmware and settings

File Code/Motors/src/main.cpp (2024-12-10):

/**
 * @file PIDMotorControl.ino
 * @brief Implements PID motor control using an encoder for feedback.
 * 
 * This program controls a motor using PID to maintain a target speed.
 * It uses encoder feedback to calculate the motor speed and adjusts
 * the motor PWM signal accordingly.
 */

#include <Arduino.h>

// Motor and Encoder Pins
#define MOTOR_IN1 25   ///< Motor input pin 1 connected to GPIO 25
#define MOTOR_IN2 26   ///< Motor input pin 2 connected to GPIO 26
#define ENCODER_A 27   ///< Encoder A pin connected to GPIO 27
#define ENCODER_B 9    ///< Encoder B pin connected to GPIO 9

// PID Constants
const float Kp = 0.5;  ///< Proportional gain
const float Ki = 0.1;  ///< Integral gain
const float Kd = 0.01; ///< Derivative gain

// Global variables
volatile int encoderCount = 0; ///< Tracks the encoder counts
int targetSpeed = 50;          ///< Desired speed in encoder counts per second
int motorSpeed = 0;            ///< PWM duty cycle for motor
int prevEncoderCount = 0;      ///< Previous encoder count for speed calculation
unsigned long prevTime = 0;    ///< Previous time for speed calculation
float integral = 0;            ///< Accumulated integral error
float prevError = 0;           ///< Previous error for derivative calculation

/**
 * @brief Interrupt Service Routine for the encoder.
 * 
 * This ISR updates the encoder count based on the direction of rotation.
 */
void IRAM_ATTR encoderISR() {
  int stateA = digitalRead(ENCODER_A);
  int stateB = digitalRead(ENCODER_B);
  if (stateA == stateB) {
    encoderCount++;
  } else {
    encoderCount--;
  }
}

/**
 * @brief Arduino setup function.
 * 
 * Configures motor and encoder pins, initializes serial communication,
 * and attaches interrupts for the encoder.
 */
void setup() {
  // Configure motor control pins
  pinMode(MOTOR_IN1, OUTPUT);
  pinMode(MOTOR_IN2, OUTPUT);

  // Configure encoder pins
  pinMode(ENCODER_A, INPUT_PULLUP);
  pinMode(ENCODER_B, INPUT_PULLUP);

  // Attach interrupts for the encoder
  attachInterrupt(digitalPinToInterrupt(ENCODER_A), encoderISR, CHANGE);
  attachInterrupt(digitalPinToInterrupt(ENCODER_B), encoderISR, CHANGE);

  // Start Serial Monitor
  Serial.begin(115200);
}

/**
 * @brief Arduino loop function.
 * 
 * Calculates motor speed using encoder feedback, applies PID control,
 * and adjusts the motor's PWM duty cycle to maintain the target speed.
 */
void loop() {
  unsigned long currentTime = millis();
  unsigned long elapsedTime = currentTime - prevTime;

  // Calculate speed in encoder counts per second
  int encoderDelta = encoderCount - prevEncoderCount;
  float speed = (encoderDelta / (float)elapsedTime) * 1000.0; // counts per second
  prevEncoderCount = encoderCount;
  prevTime = currentTime;

  // PID control
  float error = targetSpeed - speed;
  integral += error * (elapsedTime / 1000.0);
  float derivative = (error - prevError) / (elapsedTime / 1000.0);
  motorSpeed += Kp * error + Ki * integral + Kd * derivative;
  prevError = error;

  // Constrain motor speed to valid PWM range (0-255)
  motorSpeed = constrain(motorSpeed, 0, 255);

  // Drive the motor forward: IN1 gets PWM signal, IN2 is LOW
  analogWrite(MOTOR_IN1, LOW);
  digitalWrite(MOTOR_IN2, motorSpeed);

  // Print debug information
  Serial.print("Speed: ");
  Serial.print(speed);
  Serial.print(" | Target Speed: ");
  Serial.print(targetSpeed);
  Serial.print(" | Motor PWM: ");
  Serial.println(motorSpeed);

  delay(100); // Loop delay for stability
}

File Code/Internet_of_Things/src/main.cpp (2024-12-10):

#include <Arduino.h>
#include "PrintStream.h"
#include <WiFi.h>
#include <WebServer.h>
#include <Adafruit_MLX90640.h>
#include <Wire.h>
#include <SPI.h>

// Define the MLX90640
Adafruit_MLX90640 mlx; ///< Instance of the MLX90640 thermal camera.
#define MLX90640_I2C_ADDR 0x33 ///< I2C address of the MLX90640 sensor.
#define WIDTH 32              ///< Width of the thermal image.
#define HEIGHT 24             ///< Height of the thermal image.
float mlx90640Frame[WIDTH * HEIGHT]; ///< Array to store thermal image data.

// WiFi credentials
const char* ssid = "Predator_Bot"; ///< WiFi SSID for the access point.
const char* password = "Gabi405!"; ///< WiFi password for the access point.
IPAddress local_ip(192, 168, 5, 1); ///< Local IP address of the ESP32.
IPAddress gateway(192, 168, 5, 1);  ///< Gateway IP address.
IPAddress subnet(255, 255, 255, 0); ///< Subnet mask for the WiFi network.

// Web Server
WebServer server(80); ///< HTTP web server instance.

/**
 * @brief Initializes the WiFi as an access point.
 */
void setup_wifi(void) {
    Serial.println("Setting up WiFi access point...");
    WiFi.mode(WIFI_AP);
    WiFi.softAPConfig(local_ip, gateway, subnet);
    WiFi.softAP(ssid, password);
    Serial.println("done.");
}

/**
 * @brief Generates an HTML header for the webpage.
 * 
 * @param a_string Reference to the HTML string being constructed.
 * @param page_title Title of the webpage.
 */
void HTML_header(String& a_string, const char* page_title) {
    a_string += "<!DOCTYPE html> <html>\n";
    a_string += "<head><meta name=\"viewport\" content=\"width=device-width, initial-scale=1.0, user-scalable=no\">\n<title>";
    a_string += page_title;
    a_string += "</title>\n";
    a_string += "<style>html { font-family: Helvetica; display: inline-block; margin: 0px auto; text-align: center;}\n";
    a_string += "body{margin-top: 50px;} h1 {color: #4444AA;margin: 50px auto 30px;}\n";
    a_string += "p {font-size: 24px;color: #222222;margin-bottom: 10px;}\n";
    a_string += "</style>\n</head>\n";
}

/**
 * @brief Handles HTTP requests to the root page.
 */
void handle_DocumentRoot() {
    Serial.println("HTTP request from client");

    String a_str;
    HTML_header(a_str, "ESP32 Thermal Camera");
    a_str += "<body>\n<div id=\"webpage\">\n";
    a_str += "<h1>Thermal Camera Data</h1>\n";
    a_str += "<p><a href=\"/toggle\">Toggle LED</a></p>\n";
    a_str += "<p><a href=\"/thermal\">Show Thermal Data</a></p>\n";
    a_str += "</div>\n</body>\n</html>\n";
    server.send(200, "text/html", a_str);
}

/**
 * @brief Handles HTTP requests for thermal camera data.
 */
void handle_ThermalData(void) {
    String thermal_data = "<!DOCTYPE html> <html><body>\n";
    thermal_data += "<h1>Thermal Camera Data</h1>\n";

    int status = mlx.getFrame(mlx90640Frame);
    if (status != 0) {
        thermal_data += "<p>Error reading from MLX90640 sensor.</p>";
    } else {
        thermal_data += "<table border=\"1\"><tr>";
        // Create a table for thermal data
        for (int y = 0; y < HEIGHT; y++) {
            thermal_data += "<tr>";
            for (int x = 0; x < WIDTH; x++) {
                int index = (y * WIDTH) + x;
                float temp = mlx90640Frame[index];

                // Display temperature values in the table
                thermal_data += "<td>";
                thermal_data += String(temp, 2);
                thermal_data += "&deg;C</td>";
            }
            thermal_data += "</tr>";
        }
        thermal_data += "</table>";
    }
    thermal_data += "<br><a href=\"/\">Back to main page</a>";
    thermal_data += "</body></html>\n";

    server.send(200, "text/html", thermal_data);
}

/**
 * @brief Handles HTTP requests for undefined pages (404).
 */
void handle_NotFound(void) {
    server.send(404, "text/plain", "Not found");
}

/**
 * @brief Configures the MLX90640 thermal camera.
 */
void setup_MLX90640() {
    Wire.begin(21, 22, 400000); // SDA: 21, SCL: 22, Clock Speed: 400kHz
    if (!mlx.begin(MLX90640_I2C_ADDR, &Wire)) {
        Serial.println("Failed to find MLX90640. Check connections and address!");
        while (1);
    }
    mlx.setMode(MLX90640_CHESS);           // Chess mode for reduced noise
    mlx.setResolution(MLX90640_ADC_18BIT); // Highest resolution
    mlx.setRefreshRate(MLX90640_8_HZ);     // Refresh rate: 8 Hz
    Serial.println("MLX90640 configuration complete.");
}

/**
 * @brief Main setup function for the ESP32.
 */
void setup() {
    Serial.begin(115200);
    while (!Serial) { }
    Serial.println("Starting ESP32 Web Server...");

    setup_wifi();

    // Setup MLX90640
    setup_MLX90640();

    // Configure WebServer routes
    server.on("/", handle_DocumentRoot);
    server.onNotFound(handle_NotFound);

    server.begin();
    Serial.println("HTTP server started");
}

/**
 * @brief Main loop function for the ESP32.
 */
void loop() {
    server.handleClient();
}
